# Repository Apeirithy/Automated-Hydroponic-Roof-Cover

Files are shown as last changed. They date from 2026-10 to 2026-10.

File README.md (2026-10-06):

# Automated Hydroponic Roof Cover (Rain Protection System)
An automated hardware system designed to shield hydroponic plants from rain, preventing nutrient leaching and overwatering. This project is a purely hardware-driven embedded system (no microcontrollers) that relies on analog circuit logic, sensors, and custom mechanical design.

## Project Demonstration
* **Live Demo Video:** https://youtu.be/wRM6VF9FyS4
* **Documentation & Building Process:** https://youtu.be/xM9J6tyTu58

## Hardware & Circuit Logic
The system's automation is driven entirely by analog components:
* **Rain Sensor & Op-Amp Comparator:** Detects rainwater and uses an Operational Amplifier as a comparator to output a high/low signal based on the sensor's moisture level.
* **DPDT Relay:** Reverses the polarity of the DC Gearbox Motors to roll the tarp open or closed depending on the weather conditions.
* **Limit Switches:** Acts as an endpoint detection mechanism to automatically cut off the motor current when the roof is fully opened or fully closed, preventing mechanical overextension.

## Mechanical Design & 3D Printing
The physical structure was custom-designed to integrate seamlessly with the electrical components:
* **Belt and Pulley System:** Translates the motor's rotational motion into linear motion to pull the sliding bar and unroll the tarp.
* **Rapid Prototyping:** Key mechanical components and mountings were 3D modeled and 3D printed for precise dimensional accuracy.
* **Custom Guide Pipe:** Designed and implemented a guide pipe above the roller to solve real-world mechanical misalignment issues, ensuring the tarp unrolls perfectly without folding backward.

## Project Documents
All comprehensive academic reports, including problem identification, progress reports, and final evaluations, can be found in the [Reports folder](./Reports).

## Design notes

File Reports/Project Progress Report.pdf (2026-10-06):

Automatic Hydroponic Plant Protection from rain

### 1. Introduction:

This project aims to design an automatic hydroponic plant cover that will shield the hydroponic plants from rain to maintain the nutrients by preventing it from leaching and overwatering. This report documents the entire progress of the project up to this point, before the final Project Result & Evaluation stage, detailing the product design, construction, testing, and troubleshooting of the circuit.

### 2. Work Completed to Date:

- Detailed Description of Progress:
Since the beginning of the project, we have made significant technical progress in both the electronic and mechanical aspects of the system. The goal of the project was to design an automatic rain protection cover for a hydroponic system, controlled via rain detection and motor actuation. Below are the key tasks that have been completed:

Design Finalization:
We completed the circuit schematic design using simulation software and finalized the PCB layout using a design tool compatible with our fabrication method. Simultaneously, the mechanical design for the actuator frame and roof structure was developed.

Component Procurement:
All major components required for the electronic and mechanical systems were identified and purchased. This includes resistors, the LM741 op-amp, BC547 transistor, relays, N20 DC motors, limit switches, diodes, connectors, potentiometers, and mechanical frame materials (e.g., PVC pipes).

Circuit Simulation and Breadboard Testing:
The circuit was initially simulated using the Falstad simulator to verify the behavior of the rain sensor detection system and relay actuation. The same circuit was then prototyped on a breadboard, confirming that the comparator correctly responded to varying resistance simulating wet and dry conditions.

PCB Fabrication and Assembly:

A custom PCB was designed and fabricated. Components were soldered onto the PCB, and the assembled board was tested for continuity and correct functionality. The final assembled circuit matched the expected output from the breadboard prototype and simulations.

Mechanical Design and Assembly:
3D models were created for critical mounting structures, including the motor holder, shaft adapter, and limit switch brackets. These parts were 3D printed and assembled on a PVC board frame.

System Integration:
The electronic and mechanical subsystems were combined, including limit switches to detect roof open/close position. A full test was conducted to check the integration of the actuator with the rain detection system, with the motor responding appropriately based on simulated rain input.
- Circuit Diagram (Final Version)

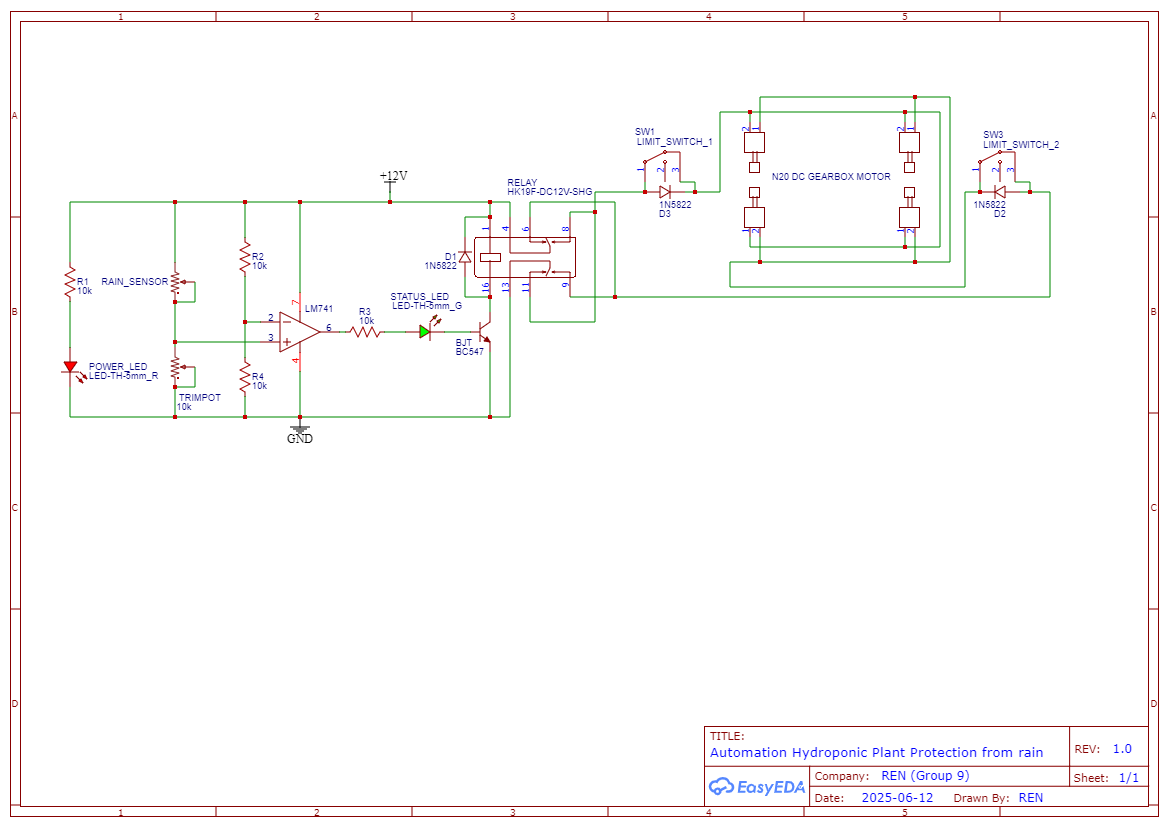
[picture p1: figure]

1. LM741 comparator.

2. Voltage divider using rain sensor and a 10kΩ resistor.
3. Adjustable threshold using a 10k potentiometer.
4. BC547 transistor and flyback diode.
5. Relay and four N20 Gearbox DC motors.
6. Limit switches integrated to control motor stop positions.

Changes from earlier version:
1. R1 and R3 increased to 10k (from 1k).
2. DC Gearbox Motors increased to 4 units (from 1).
3. Added LM741 comparator; its non-inverting input connected to voltage divider (rain sensor + trimpot). Previously, the voltage divider directly biased the BC547 base.
4. Status LED moved to op-amp output (previously at BC547 collector).

These changes were made to improve accuracy of rain detection, reducing unnecessary current usage, increase mechanical strength to roll the tarp roof, and ensure more reliable output indication through the op-amp.

- Component Status:
1. All required components have been acquired.
2. All components have been tested during breadboard and PCB-level testing.
3. No major component failures were encountered. However, relay triggering required adjustment of the comparator threshold (solved with potentiometer tuning).
4. Additional PVC pipes and reinforcement materials were purchased after initial mechanical testing revealed structural flexibility.
- Testing and Results (Up to this point):
1) Testing Performed:
a. Simulations in Falstad and on breadboard.
b. Measurements of voltage across op-amp outputs and relay.
c. Relay response and transistor saturation behavior confirmed.
d. Full system test with motor actuation and limit switch stopping.
2) Results:
a. Comparator switches at expected thresholds (based on ~6V reference).
b. Relay successfully triggered at sensor resistance below ~5kΩ.

c. Motors operated correctly, stopping at limit switch positions.
d. Current draw remains below 1A (safe for 12V power supply).
e. The final PCB circuit behaves identically to the simulated version.
- Challenges Encountered and Solutions:
A. Relay Not Triggering Properly:
Caused by mismatch in comparator voltage. Solved by adjusting resistor values and installing a 10k potentiometer for fine tuning.
B. Frame Instability:
Early frame was too weak. Reinforced with screws
C. Limit Switch Misalignment:
Fixed by redesigning brackets in CAD and reprinting for better fit.
D. Motor Control Glitches:
Traced back to lack of flyback protection. Fixed by installing diodes across relay and motor terminals.

### 3. Visual Evidence:

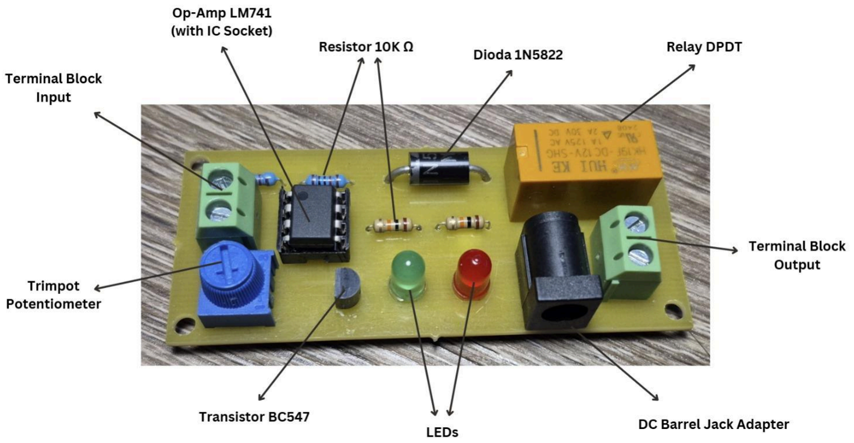
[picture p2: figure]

Rangkaian Utama pada PCB

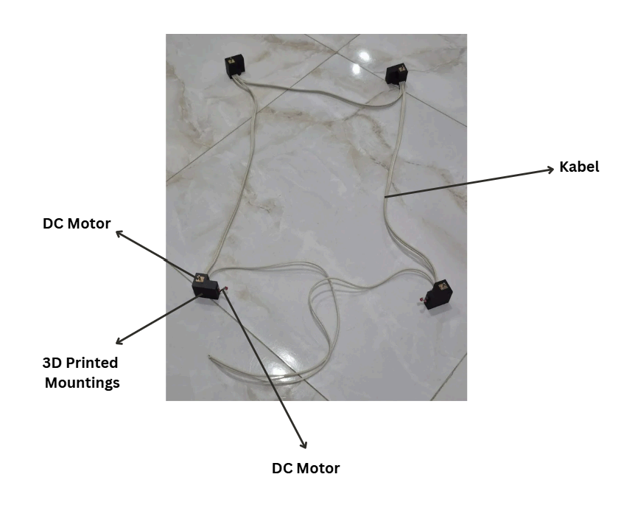
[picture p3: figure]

Rangkaian Limit Switch dan DC Motor

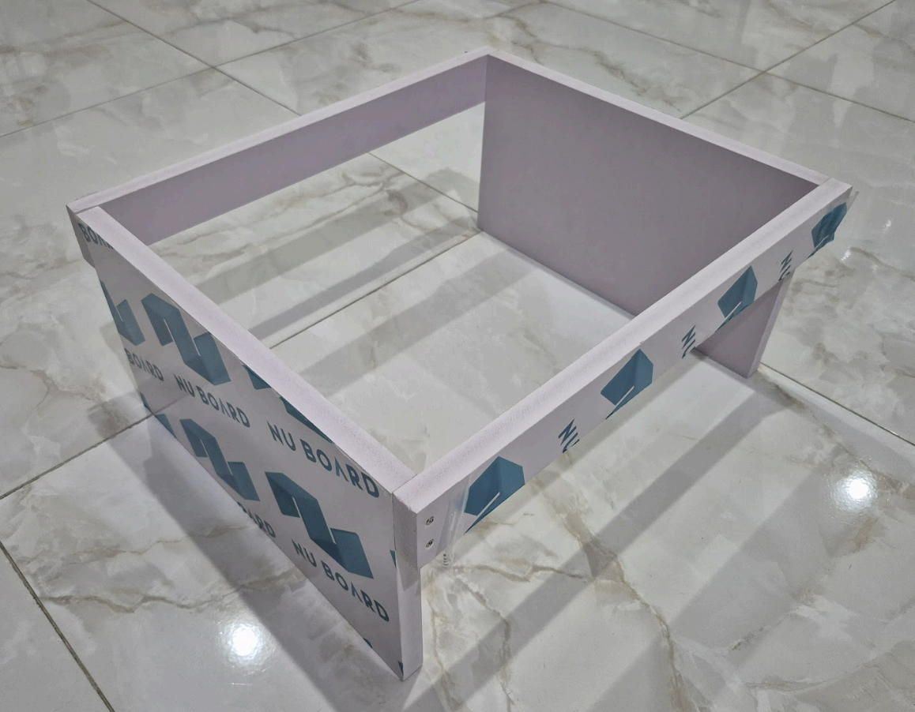
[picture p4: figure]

Bingkai Pot dan Atap Menggunakan PVC Foam Board

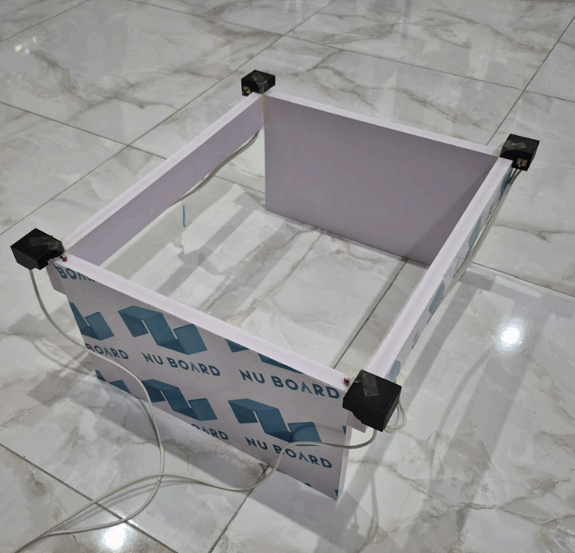
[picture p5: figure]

Memasang Rangkaian Limit Switch dan DC Motor pada Bingkai

### 4. Reflection and Planning:

- Reflection on Progress (Entire Project to Date):
Looking back on the project from the initial planning to the current integrated system, we can say that our progress has been steady and close to our expected timeline. Most milestones were achieved on time, though some stages—particularly mechanical assembly—took longer than anticipated due to adjustments in the frame design and component fit. We have gained significant experience in both circuit design and mechanical system integration. What went particularly well was our ability to validate our design through simulation (Falstad) and transfer it successfully to a functioning PCB. If there’s one area we could have improved, it would be more detailed planning of the mechanical side in the early stages, as some of the redesigns could have been avoided.
- Challenges and Lessons Learned (Entire Project to Date):
Throughout the project, we faced several key challenges that became valuable learning moments. One challenge was fine-tuning the comparator circuit so that the relay would trigger consistently under varying rain sensor conditions. This taught us the importance of adjustability, which we solved by replacing fixed resistors with potentiometers. Another issue was the physical instability of the initial PVC frame, which required reinforcement and custom 3D-printed parts. We also encountered alignment problems with limit switches, which affected the actuator stopping mechanism. Through these challenges, we learned the importance of prototyping early and being flexible in our design approach. We also improved our teamwork and problem-solving skills by dividing tasks efficiently and responding quickly to problems.
- Current Status and Next Steps (Leading to Final Evaluation):
Currently, the project is functionally complete. The circuit is fully operational and mounted on a PCB, the actuator system is assembled and integrated with the rain detection circuit, and the motors successfully respond to rain conditions by opening and closing the hydroponic cover. All sensors, switches, and relays have been tested.

What remains before the final evaluation:
A. Conduct extended testing in real environmental conditions (e.g., water droplets, different rain intensities).
B. Finalize and clean up wire management and mechanical mounting for presentation.
C. Collect video/photo documentation and performance data (e.g., response time, current consumption).
D. Prepare the final project report and presentation slides.
E. Our goal for the final stage is to ensure the system is not only functional but also reliable and presentable, ready for demonstration during the final evaluation.

Progress documentation:
https://drive.google.com/drive/folders/1GFRt7rV3YSRr9KsO9saTGnvedaAOEba6?usp=shar ing (https://drive.google.com/drive/folders/1GFRt7rV3YSRr9KsO9saTGnvedaAOEba6?usp=sharing)

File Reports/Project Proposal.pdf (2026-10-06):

Automation Hydroponic Plant Protection from rain

### 1. Introduction:

Hydroponic farming offers advantages like minimal land use and easy maintenance, making it ideal for urban areas (Ilhamdi et al., 2018; Harsono, 2020). However, outdoor setups are vulnerable to rain, leading to overwatering, nutrient leaching, and reduced yield quality. While indoor farming provides protection, it requires costly artificial lighting, and mini greenhouses still need manual adjustments (Kusumawati & Untoro, 2022). This project aims to develop an automated hydroponic plant cover using a purely analog control system with a rain sensor and actuators to protect plants from rain, enhance growth, and reduce human intervention.

### 2. Proposed Solution/Design:

The proposed solution involves an automatic cover system for hydroponic plants that operates based on rain detection. The system consists of a purely analog circuit that detects rainfall using a rain drop sensor and actuates a protective plastic cover.

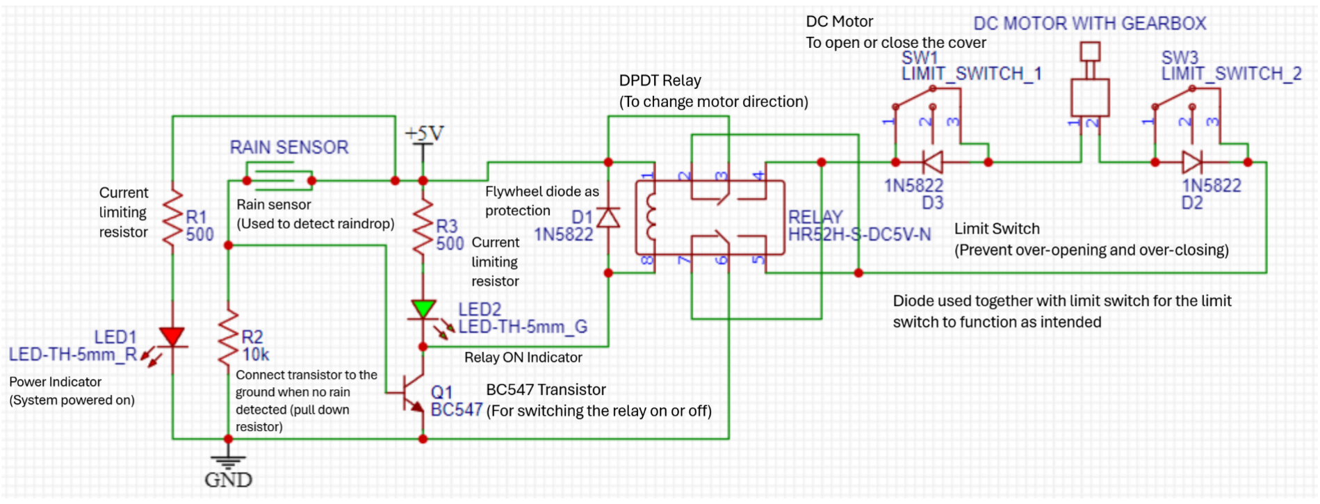
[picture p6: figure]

- Rain Detection Mechanism:
- A rain drop sensor will detect water droplets and trigger a switching circuit that controls the plastic cover’s movement.
- A relay system will be used to actuate the cover through a gearbox DC motor.

- Component Selection Justification:
- Rain Drop Sensor: The raindrop sensors are chosen as rain detection instruments because they are easy to find and affordable.
- Transistor (BC547): The BC547 NPN transistor was chosen for its common usage, availability, and its ability to handle the current required by the DPDT relay (100 mA maximum current vs 10 mA needed by DPDT).
- DPDT Relay: DPDT relay was chosen for its availability and its ability to control the directional movement of the gearbox DC motor.
- Gearbox DC Motor: Gearbox DC motor provides high torque while keeping the price affordable. Its high torque enabled the plastic cover to protect the plants from rain.
- Light Emitting Diode: Used as an indicator to indicate state of sensor activation and idle status. LEDs were chosen because they are energy efficient and inexpensive, reducing unnecessary energy waste (only use around 10mA of current).
- 1N5822 Diode: Used in conjunction with a limit switch to allow the motor to rotate in a limited manner and as a flywheel diode for protection. This diode was chosen due to its low price and easy to find.
- Working Principle:
When powered on, the red LED lights up as a power indicator. If water drops onto the rain drop sensor, the conductivity of the rain drop sensor will increase, causing the transistor to activate, triggering the relay, which in turn drives the motor to pull the plastic cover over the plants. At the same time, the green LED lights up as an indicator. The motor will continue moving the cover until it reaches the limit switch, signaling that the plants are fully covered, and the motor stops. Once the rain stops, the conductivity of the rain drop sensor will decrease, causing the transistor to deactivate, turning off the relay, causing the motor to retract the cover. The green LED turns off, indicating that the cover is retracting. The motor will keep retracting the cover until it reaches the original position and triggers the limit switch, stopping the motor.

Calculations:
Current through 500Ω resistor (to the indicator LED):

I =

V
R =

5
500 = 0. 01 A = 10 mA

### 3. Project Timeline:

- Week 1-4: Research and selection of components, schematic design, initial circuit simulation, creation of problem identification and project proposal.
- Week 5: Project proposal presentation and feedback from lecturer.
- Week 5-7: Lecturer feedback integration and project proposal refinement.
- Week 7-8: Circuit board construction and testing of the rain detection circuit and relay switching mechanism.
- Week 9-11: Integration of circuits with actuators, refinement of control logic, and testing under simulated rain conditions.
- Week 12-13: Final system testing, data collection on plant conditions, performance evaluation, report writing, and presentation preparation.

### 4. Materials/Equipment Required:

- Gearbox DC Motor
- Connecting wires
- Resistor (500Ω, 10kΩ)
- Transistor (BC547)
- Diode (1N5822)
- LED (Red, Green)
- Rain Sensor
- DPDT Relay (Double Pole Double Throw)
- Limit Switch
- Power Adapter
- Polylactic Acid (PLA) Filament
- 3D Printer
- Roll Mica Plastic
- Paranet
- Copper/stainless steel pipe with an outer diameter of 3/8 inch

### 5. Potential Challenges and Mitigation Strategies:

- Challenge: Risk of rainwater exposure.
Mitigation: A waterproof box will be added to store the electronic components, a waterproof box will also be added to the DC motor and the gap in the box made for the cables will be sealed.
- Challenge: Rain sensor that stays wet even after the rain has finished.
Mitigation: The rain sensor is tilted slightly so that the sensor does not become flooded with water after the rain has finished.
- Challenge: Cover can be blown away by the wind.
Mitigation: designing a more sturdy cover frame and adding weights at the bottom so that the frame does not easily tip over.

### 6. Expected Outcomes:

- A fully functional automatic roof that moves from its base to cover the hydroponic plants when it is raining, and retracts when it stops raining.
- A functional polarity switching action using a DPDT relay, to determine which limit switch is activated for the roof.
- A comprehensive project report that includes:
- A detailed description of the circuit design and operation.
- A professionally drawn schematic diagram.
- A list of all components used, with justifications for their selection.
- A step-by-step explanation of the circuit's working principle.
- A description of the testing procedures and results, including any observations or issues encountered.
- An analysis of the circuit's performance and its effectiveness in protecting hydroponic plants from rain water.
- A discussion of any challenges encountered during the project and the mitigation strategies employed.
- Suggestions for future improvements or extensions to the project.
- An engaging project presentation that delivers the project’s goals, methodology, and how the project solves the problem.

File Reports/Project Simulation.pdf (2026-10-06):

Automatic Hydroponic Plant Protection from rain

### 1. Introduction:

This simulation explores the behavior of an automated hydroponic plant cover system, which automatically closes during rainfall and reopens when the rain stops. The simulation focuses on verifying the activation of the DC gearbox when rain is detected by the sensor, and on ensuring that both limit switches correctly stop the motor when the cover reaches its fully closed or fully opened positions.

### 2. Simulation Setup and Design:

Falstad circuit simulator was used for the circuit simulation. The simulated circuit diagram closely followed the schematic from the project proposal, with a few adjustments to reflect the latest design changes based on the progress report.

Default Falstad components models were used for most of the components, except for the op-amp, which was configured to simulate the LM741 as used in the actual circuit. The relay coil resistance was set to 320Ω, based on the datasheet assumption that the coil consumes approximately 0.45 watts of power. A 12V DC voltage source was used to represent the 12V power adapter.

The rain sensor's behavior was simulated using a potentiometer configured as a rheostat. Its resistance was manually varied during the simulation to represent the change in conductivity of the rain sensor surface when wet and dry.

Simulations were performed to observe the circuit's switching behavior as the rain sensor resistance changed, representing the presence or absence of raindrops on the sensor surface.

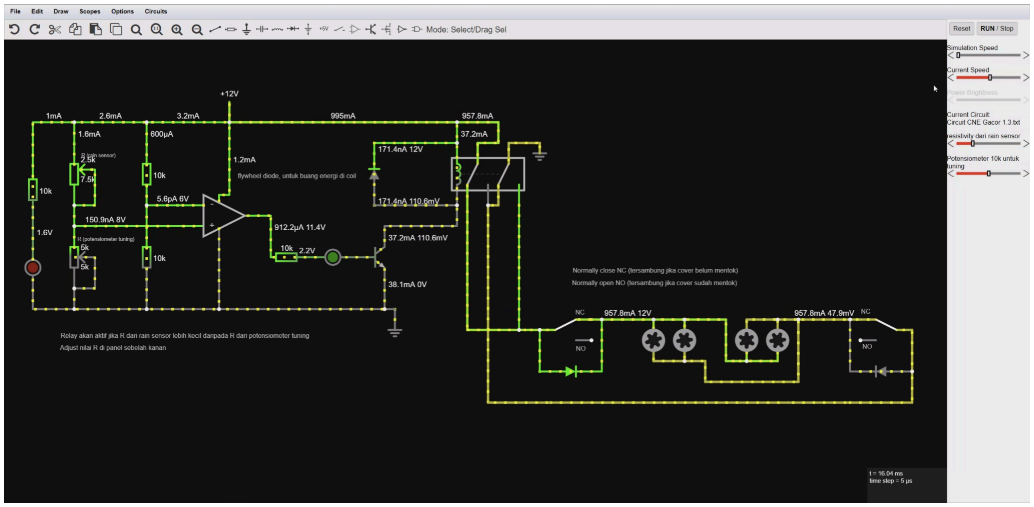
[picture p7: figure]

Figure 1: Simulation screenshot when rain is detected (sensor surface wet)

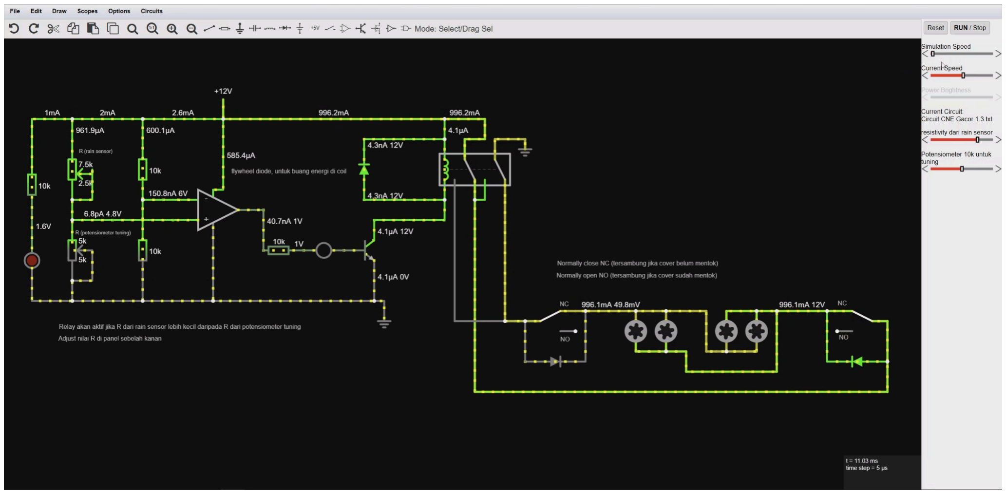
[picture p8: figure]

Figure 2: Simulation screenshot when rain stops and sensor surface dries

Component Models:
Default Falstad models were used for all components except as noted above. The rain sensor was simulated by using a potentiometer in rheostat mode, with manual adjustment of resistance values during the simulation to represent varying levels of wetness on the sensor surface.

Simulation Parameters:
The simulation was run without a predefined time duration. Instead, it was stopped when the total current drawn from the 12V supply approached the power adapter's current rating (1A). The rheostat resistance that simulates the rain sensor resistance was adjusted manually during the simulation to explore behavior at two main points: when the rain sensor resistance is lower than the tuning rheostat resistance, and when the rain sensor resistance is higher than the tuning rheostat resistance. These two points reflect the threshold behavior of the comparator circuit. Default Falstad simulation settings were used throughout to ensure consistency.

Test Circuits:
The primary simulation focused on the complete rain detection and motor control circuit. No separate test circuits were used for individual subsystems, as the focus was to evaluate the behavior of the fully integrated system.

### 3. Simulation Results and Analysis:

Presentation of Results:
The circuit was simulated using Falstad Circuit Simulator to test the full functionality of the rain detection and actuator control system. The simulation modeled the behavior of key components such as the LM741 comparator, BC547 transistor, relay, and N20 DC motor activation, based on rain sensor input.

The rain sensor was simulated using a potentiometer configured as a rheostat, allowing manual adjustment of resistance to represent wet and dry conditions. The switching behavior was observed in response to these changes.

Key Observations:
Condition | Rain Sensor Resistance | Op-Amp Output | Relay State | Motor Status
Dry (No Rain) | > 5kΩ | ~0V | OFF | Cover open
Wet (Rain Detected) | < 5kΩ | ~11.4V | ON | Cover closing
Rain Stops (Back to Dry) | > 5kΩ | ~0V | OFF | Cover opening

Analysis and Interpretation:
The simulation results closely matched theoretical expectations. The comparator output voltage transitioned from low (~0V) to high (~11.4V) precisely when the rain sensor resistance dropped below the reference threshold, which is set by a voltage divider or tuning potentiometer (approximately 6V reference point).

This high output activated the BC547 transistor, which saturated and allowed current to flow through the relay coil. The relay then activated the motor circuit. When the rain stopped (resistance increased), the op-amp output returned to low, the transistor cut off, and the relay deactivated.

The motor behavior followed the relay state perfectly, with forward movement during rain and reverse movement when dry, controlled by the logic implemented using limit switches.

No unexpected behavior was observed. The transitions were clean, and no chattering or unstable switching occurred, indicating that the design has appropriate hysteresis and stable operation. Minor discrepancies in switching voltage occurred due to simulation tolerances, but these were within acceptable limits and do not affect real-world behavior.

Key Parameters:
Parameter | Simulated Value | Target/Theoretical Value | Notes
Comparator Switching Voltage | ~6V (adjustable) | ~6V | Controlled via 10k potentiometer

Op-Amp High Output | ~11.4V | ~12V max (supply-limited) | Sufficient to saturate transistor
Relay Coil Resistance | 320Ω | Datasheet value | Confirmed 0.45W power draw
Relay Coil Current | ~37.2mA | Theoretical: 37.5mA | Matches with 12V / 320Ω
Total Current Draw (Active) | ~957.8mA | Limit: < 1A (adapter max) | Safe operating range

### 4. Comparison with Theoretical Calculations:

The calculated switching threshold for the comparator was based on the resistor divider formed by the rain sensor and the tuning potentiometer. At rain detection, the rain sensor resistance drops to around 2.5kΩ, producing approximately 8V at the non-inverting input of the LM741. The reference voltage was set to 6V using a 10kΩ resistor divider.

During simulation, the comparator switched as calculated when the rain sensor voltage goes above the reference voltage. The comparator output produced around 11.4V, which successfully drove the BC547 transistor into saturation, allowing approximately 37.2mA to flow through the relay coil. This activated the motor circuit, drawing a total current of about 957.8mA from the 12V power supply.

The simulation results are within a few percent of the calculated values, validating both the accuracy of the design calculations and the simulation model. Minor differences can be attributed to simulation simplifications, such as component tolerances and the simplified models used in the simulation.

### 5. Conclusion:

The simulation results confirmed that the circuit performs as expected based on the project’s design goals. The comparator accurately responded to changes in the rain sensor resistance, switching the output at the appropriate threshold and correctly activating the relay and motor system. This behavior aligns with the intended function of automatically closing the hydroponic cover during rain and reopening it once conditions are dry.

Through the simulation process, we gained a deeper understanding of how component values such as resistor selection and reference voltage affect the circuit’s sensitivity and reliability. We also identified areas for improvement, such as adding adjustable tuning via a potentiometer to fine-tune the switching threshold. These insights allowed us to refine the circuit before building the physical prototype, saving time and reducing troubleshooting later in the project.

Overall, the simulation validated the functionality of the entire system and provided confidence to proceed with PCB fabrication and full mechanical integration. It played a crucial role in ensuring our design is both effective and efficient in achieving its purpose: protecting hydroponic plants from excess rain automatically.

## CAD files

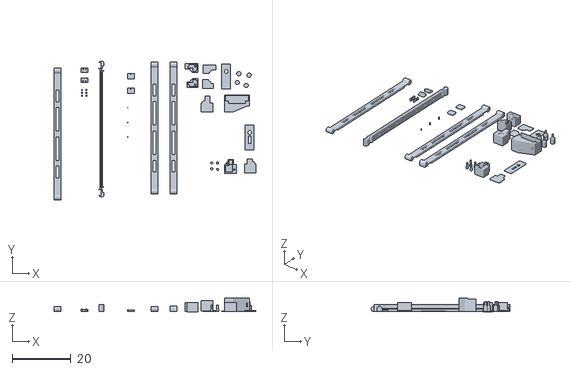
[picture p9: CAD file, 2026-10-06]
3D_Models/CnE 3D File.stl
68.9 x 47.4 x 4.65

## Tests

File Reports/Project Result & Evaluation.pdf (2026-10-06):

Automation Hydroponic Plant Protection from Rain

### 1. Introduction:

This project aims to design an automatic hydroponic plant cover that will shield the hydroponic plants from rain to maintain the nutrients by preventing it from leaching and overwatering. This report details the project outcomes and performance, design effectiveness, lessons learned and evaluation of the project.

2. Project Outcomes and Performance;
- Functionality:
The final circuit successfully functions as intended. When it is raining the rain sensor detects the rainwater, causing the motors to spin and roll open the roof using a belt system. When the roof has opened all the way, the sliding bar hits the limit switch and stops the bar from pulling the roof. When the rain is over and the rain sensor is dry, the motors start spinning in reverse to close the roof until the bar hits the first limit switch where the bar rests at the beginning before the rain, resulting in the roof rolls up perfectly back to where it started.
- Performance Analysis:
The performance of the system can be viewed from some aspects:
1. Responsiveness
The system responds promptly to rainfall detection, with the motor activating within approximately 1 second after the rain sensor becoming wet. This quick response helps to prevent plants from being exposed to early drops of rain.
2. Transition Accuracy
The use of limit switches provides reliable endpoint detection, preventing the tarp from overextending. During testing, the tarp consistently stopped at the desired position both when opening and closing.
3. Mechanical Stability
Mechanically, the system performs reliably. The use of a belt and pulley system allows for smooth tarp movement. No slippage or mechanical failure was observed during repeated tests.

Overall, the system demonstrates strong performance in both electrical and mechanical aspects. Rain detection triggers the tarp unrolling sequence with minimal delay. Limit switches effectively prevent over-extension of the tarp, and the belt mechanism ensures smooth and failure-free operation. No functional or electrical failures were observed, and the system returned to its default position reliably after each cycle.

- Circuit Diagram (Final Version):

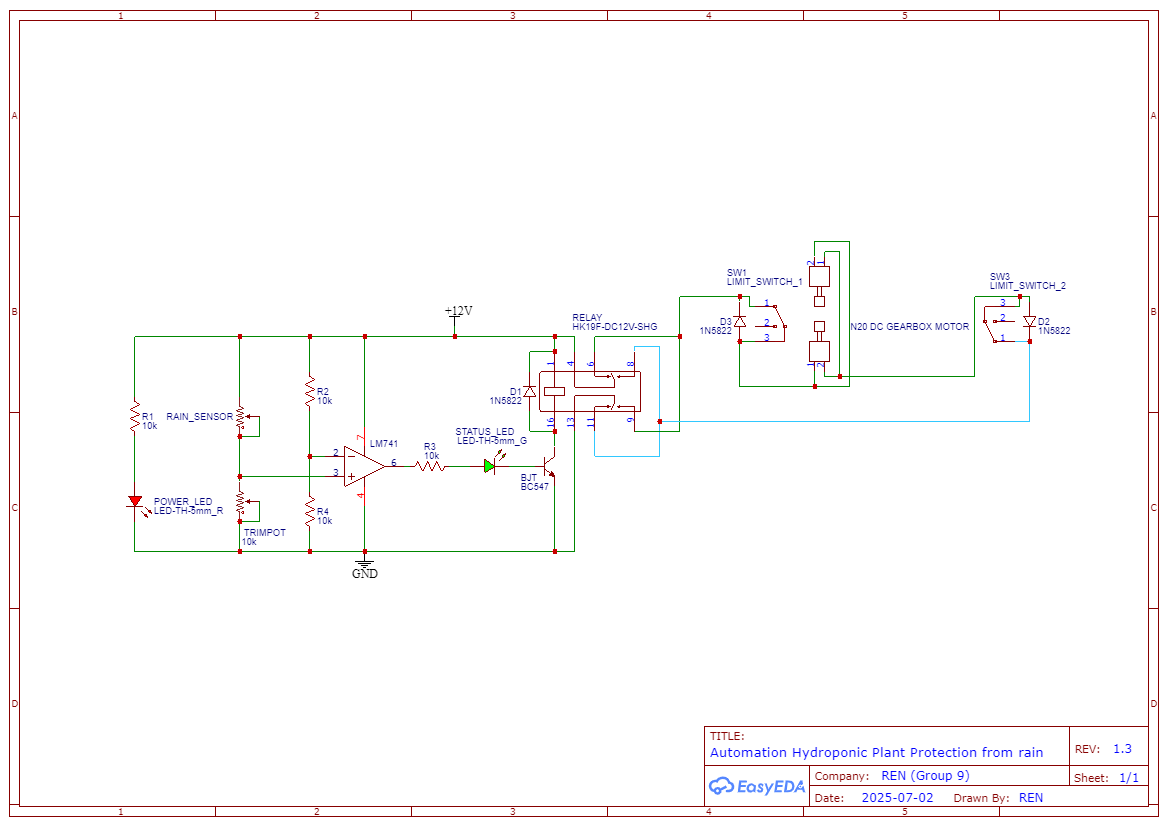
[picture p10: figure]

- Component Performance:
All of the components performed as expected. The rain sensor effectively senses rain water. The Op-Amp successfully works as a comparator whether the rain sensor is wet or dry. The BJT successfully controlled the current for switching the pole in the DPDT relay. The DPDT relay successfully controlled the direction of rotation of the motor. The diodes successfully kept the current flow through the limit switch only, making the limit switches effectively functional to stop the current from flowing when the switch is pressed. The limit switches effectively stops the current from flowing when the rod presses the limit switch, which is when the roof is fully open or fully closed.
- Power Consumption Analysis:
The measured power consumption is relatively low, making it suitable for continuous operation using a 12V power supply. Below is the breakdown of the current consumption during each operation cycle:
1. Idle state with sensor dry and tarp fully rolled:
❖ Current: ~2 mA
❖ In this state, the op-amp output is off, and the motor is not active. The system only draws minimal current for sensor monitoring and power indicator.
2. Tarp unrolling (rain detected, motor opening the tarp):
❖ Current: ~345 mA
❖ This is the highest power consumption phase, as the motor is actively working to unroll the tarp to cover the plants.
3. Fully unrolled state (rain detected, tarp fully opened):
❖ Current: ~19 mA
❖ The motor has stopped moving. Current consumption in this state comes mainly from active op-amp circuit and relay holding current.
4. Tarp rolling back (sensor dry, motor retracting the tarp):
❖ Current: ~320 mA
❖ The motor is again active, but slightly lower current than during unrolling, due to inactivity of the op-amp circuit and inactivity of relay when pulling the tarp.

Overall, the system remains energy efficient, with high current draw only during motor activation phase (unrolling and rolling the tarp). In idle states, the consumption is minimal, averaging between 2 mA and 19 mA, ensuring that the system does not impose significant load on the power supply when inactive.

### 3. Design and Implementation Evaluation:

- Design Effectiveness:

The system design functions smoothly and effectively fulfills its intended purpose. The automatic cover mechanism, driven by a motor, responds reliably to the rain sensor, opening and closing the tarp without error. The limit switches accurately detect the end positions and prevent overextension. There is still room for improvement—future iterations could benefit from implementing reed (magnetic) switches to reduce mechanical wear and a belt tensioning mechanism to allow tension adjustments without disassembling the system.
- Implementation Quality:
The prototype is practical and ready for real-world outdoor application. The structure is water-resistant, and the mechanical-electrical integration works reliably. The entire system can operate immediately in a hydroponic environment. However, the component mounting process still requires improvement. Using proper fixtures such as screws or brackets instead of relying on glue gun or super glue would result in a more durable and professional build.
- Component Selection Evaluation:
Component selection was appropriate and well-matched to the system’s requirements. Each component—rain sensor, op-amp as comparator, DPDT relay, and limit switches—performed as expected. The decision to reduce the number of motors from four to two was particularly effective, as it simplified the system and resolved previous synchronization issues without compromising power or functionality.

### 4. Challenges and Lessons Learned:

- Summary of Key Challenges:
- Creating multiple early prototypes quickly helped identify design flaws early in the process.
- 3D modeling was a significant and time consuming hurdle, requiring much learning and practice to produce precise and functional parts.
- Selecting specific materials and components should have been done earlier to avoid delays.
- Ordering components too close to the deadline created timing issues and delivery concerns.

- Mounting components using super glue and glue guns was suboptimal, especially for parts under mechanical stress, as it not only led to stability concerns but also made repositioning difficult due to the permanent nature of the adhesive.
- The tarp (rain cover material) occasionally caused problems during motor operation. The motor was intended to rotate counterclockwise to unroll the tarp, but after reaching the endpoint—or after repeated use—the tarp sometimes folded incorrectly and forced the motor to reverse its direction (clockwise), This misalignment resulted in the system stopping unexpectedly or failing to operate correctly . This issue occurred because the tarp roller became loose, causing the material to fold in the wrong direction. The problem was resolved by introducing a belt drive system and installing an additional guide pipe above the roller, which ensured the tarp would exit the roller properly in the correct direction
- Lessons Learned:
- Starting the project earlier provides more time for experimentation and troubleshooting.
- Mastery of 3D printing techniques (e.g., brim, support structures) greatly improves the quality of printed parts.
- Maintaining detailed wiring documentation and circuit logic understanding from the start helps avoid assembly errors.
- Preparing backup components and considering alternatives in advance is crucial in case of failures or wrong selections.

### 5. Conclusion and Future Work:

- Overall Project Success:
The project was successful. The product and the final circuit functions as intended, meeting all the project goals. The automatic roof effectively rolls open when the rain sensor detects rainwater, and closes back when the rain sensor is dry. The performance of the circuit is stable and reliable. We are pleased with the outcome of the project.
- Future Work:

For future work, we could add a knob system for adjusting the tension of the belt without having to take off the mountings to adjust it. We also could change the limit switches into reed switches that use magnets to open or close the switch, without worrying the switch will be weary or starting to loosen after getting pressed frequently. Finally, we could make the rod slightly hover by adding more tension to the belt, to prevent the friction of the rod scraping the PVC foam board after it is used for a large amount of time.

Contribution Statement

Focus on Circuit Design, Component Selection and Team Coordination Student Name: Rafael Marvin Jonathan
Student ID: 2802416835
Contribution Statement:
“My primary contribution was in initiating the project idea and translating it into a clear concept for the team. I explained the overall functionality of the system, including how sensors, relays, and mechanical components would work together to automatically open and close a tarp based on rain detection.

Together with Nicholas, I selected the components used in the circuit. I was then responsible for designing the schematic circuit diagram and creating the PCB layout. I also performed circuit simulations both on a breadboard and using the Falstad simulator to validate the design prior to PCB fabrication.

During the hardware implementation phase, I was assisted by my team member in the PCB engraving process and in soldering components onto the board. Along with Eric and Nicholas, I planned and installed the wiring throughout the system.

I also proposed the design of the mechanical system, which incorporated a timing belt and pulley mechanism to drive the sliding bar that opens and closes the cover.

As the team leader, I coordinated meetings, delegated tasks, managed the document submission process, and took on the role of both project secretary and treasurer by keeping track of progress updates and all project-related expenditures.”

Focus on Mechanical Design, Component Selection & Installation
Student Name: Nicholas Laurensius Halim
Student ID: 2802428072
Contribution Statement:
“My primary contributions to the project focused on the mechanical design and implementation aspects. I was responsible for designing and preparing 3D models for components that were later fabricated using 3D printing, ensuring that parts were dimensionally accurate and fit well into the system. I also assisted in selecting suitable components for both electrical and mechanical functionality.

Additionally, I contributed significantly to problem-solving during the prototyping phase—such as proposing and implementing the use of an additional guide pipe above the tarp roller to ensure the tarp unrolled correctly. I actively participated in testing sessions alongside other team members and assisted in the physical installation and integration of the project components, ensuring that the system functioned smoothly as a complete unit."

Focus on Integrating Components, Product Finishing & Documentation
Student Name: Eric Christian Darmawan
Student ID: 2802391681
Contribution Statement:
"My primary contribution to the project focused on helping Nicholas and Rafael on the PCB engraving process, building the frame, and integrating the circuit to the frame. I also helped prepare and slice the 3D models made by Nicholas and Rafael before printing on the 3D printers. I also contributed in arranging the cables so the final product has a cleaner look.

Additionally, I contributed significantly to do a documentation of our team’s journey from the start of the project until the final product, and edited it for submission requirements. I took all the pictures and videos of the process, from the very first iteration of the product until the final iteration of the product.”

Hasil pemeriksaan plagiarisme dengan Turnitin

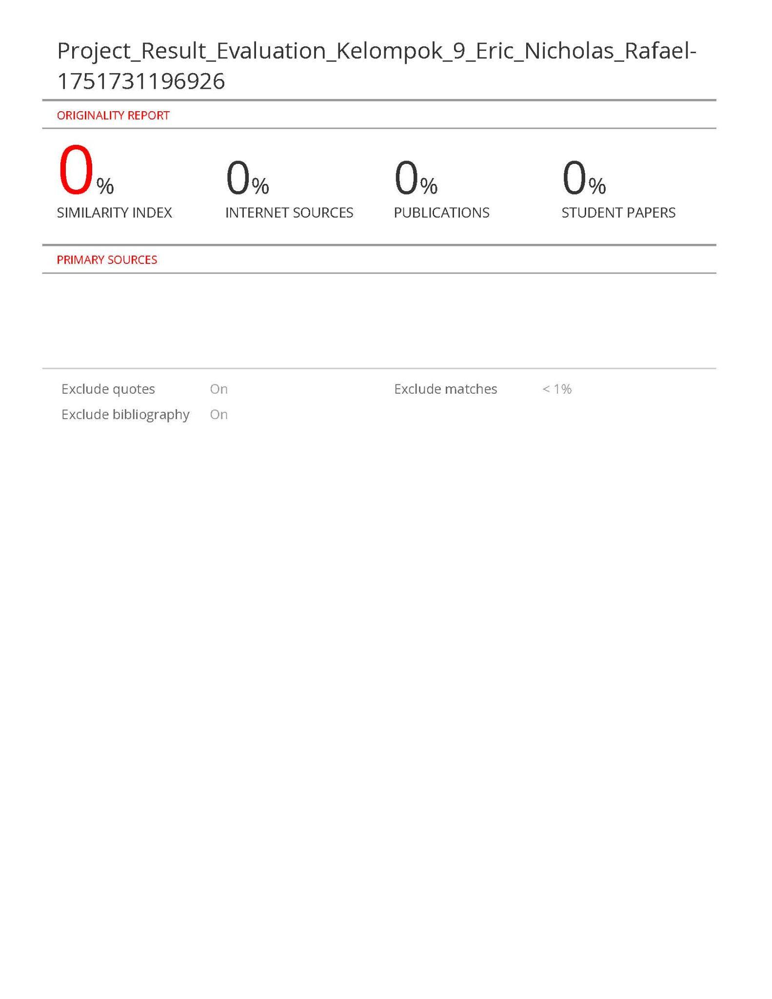
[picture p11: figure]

Hasil pemeriksaan AI dengan Turnitin

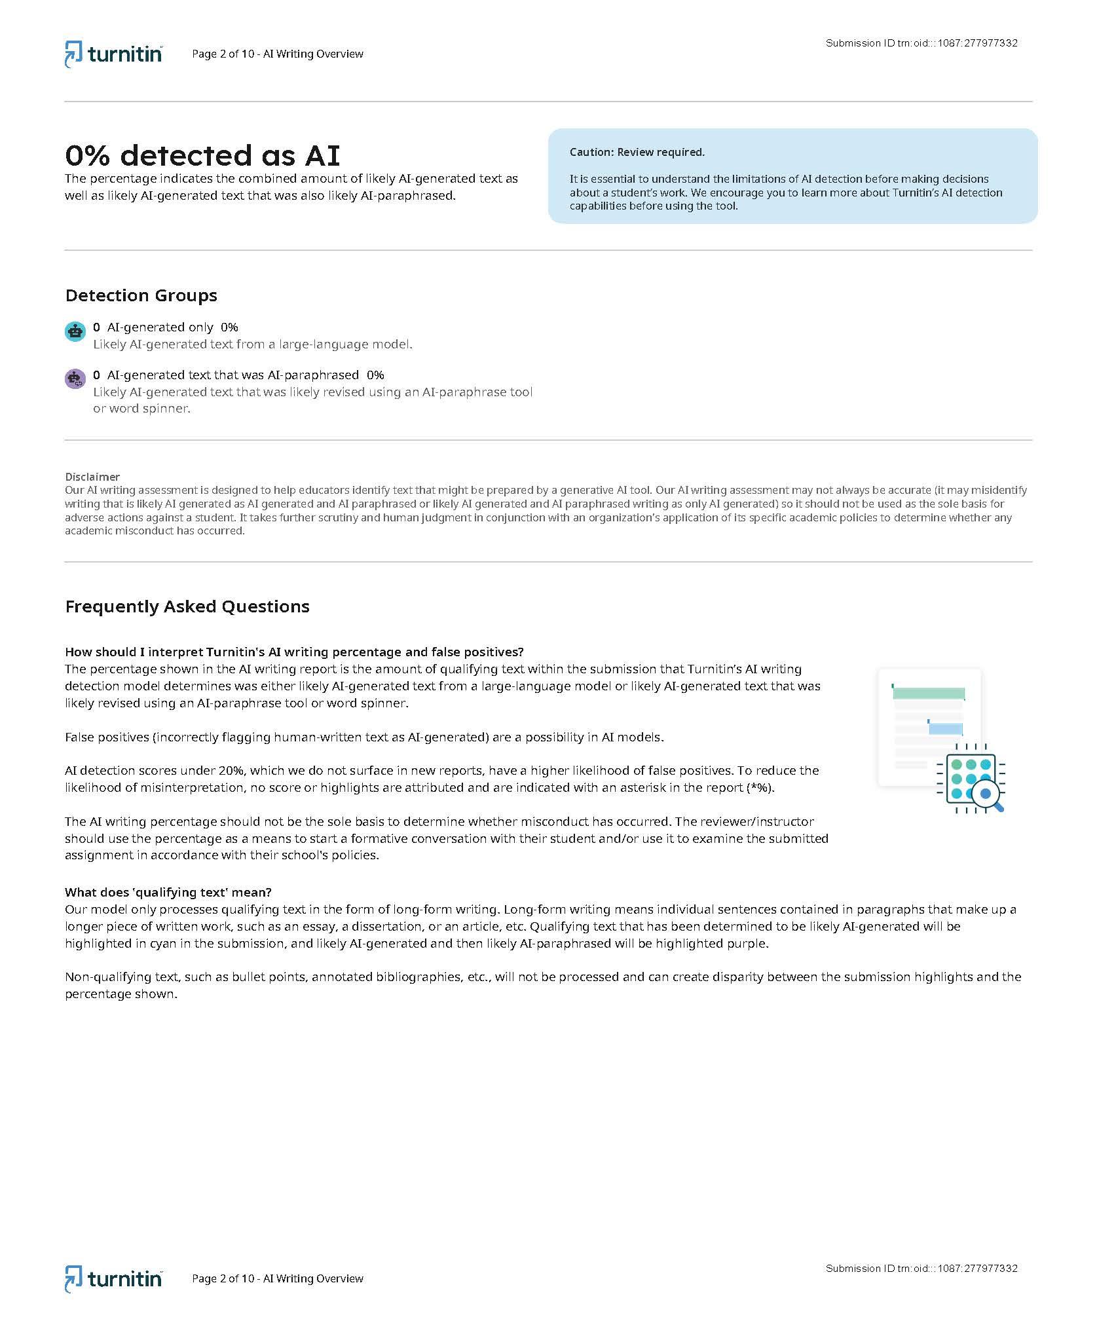
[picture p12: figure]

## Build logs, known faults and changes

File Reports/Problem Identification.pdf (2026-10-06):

Automation Hydroponic Plant Protection from rain

### 1. Introduction/Problem Statement:

"Hydroponics planting method that utilizes water containing nutrients as a growing medium offers advantages such as not requiring large land areas and easy maintenance (Ilhamdi et al., 2018). The hydroponic method allows vegetable cultivation to be carried out in urban areas such as apartment balconies, house terraces, and even indoors for those with very limited space (Harsono, 2020). Despite these advantages, planting on balconies or terraces does not protect plants from exposure to rain. Rain can cause overwatering and nutrient leaching, which may hinder optimal nutrient absorption and excessive nutrient addition. Furthermore, the impact of rain can lead to unsatisfactory harvests or even complete crop failure. While indoor planting offers protection from rain, it requires higher investment costs for ultraviolet lighting as an artificial sun. The use of a mini greenhouse outdoors, although providing protection against weather conditions, greenhouses still require human intervention to adjust temperature and humidity (Kusumawati, Untoro, 2022). This project aims to protect hydroponic plants from rain by designing an automatic cover that will shield plants with plastic when it rains. This will ensure that hydroponic plants can grow optimally despite rainy weather. The project will focus on designing a purely analog circuit with actuators and sensors to achieve the desired functionality."

### 2. Feasibility & Scope:

"This project can be completed within the timeframe given in this course. The required electronic components, such as rain drop sensor, DPDT relay, limit switch, transistor, resistor, diode, and capacitor, along with actuator components like a gearbox DC motor, are available and affordable. Materials for the plant cover, and mica plastic are also accessible. Our level of knowledge of basic circuit analysis and analog circuit design to manage this project. The project will focus on designing and implementing a core circuit that detects rain. The circuit will use a rain drop sensor for water droplets, and transistors as switches to trigger the relay. This focused scope allows concentration on essential principles of an automatic plant cover and ensures the project is manageable. More complex designs with additional features can be considered for future projects."

### 3. Feedback Integration:

“We have discussed our project idea with the lab assistant. He suggested that using a power-adapter would be beneficial. This would eliminate the need to change the batteries every time it runs out of power. We agree that this is a valuable addition. I will incorporate a power-adapter into my circuit design. He also cautioned me about the risk of water that can damage the circuit. He suggested that we should make a case to protect the circuit from contact with water.”
